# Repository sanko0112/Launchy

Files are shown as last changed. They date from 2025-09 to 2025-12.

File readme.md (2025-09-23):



### ESP32 ESP-NOW Based model rocket launch controller

## 🤌Features

- ESP-NOW Long range protocol
- Multi-layer safety: Key switch, iButton, push button
- OLED display for status feedback
- Built in battery charging circuit (TP4056)
- USB-C for programming/charging
- Internal 1S / External 2S battery selection for the e-match
- Continuity test (1S mode)
- Preheat mode(1S mode)
- Configurabe Countdown time, Ignition time
## 🔧Hardware

&nbsp;&nbsp;&nbsp;&nbsp;&nbsp;The system is based on a custom PCB designed in KiCad, built around the ESP32-C3-MINI-1 module. Both the transmitter and the igniter/receiver use the same board design, but are populated with different component sets depending on their role. The
hardware integrates Li-Ion charging (TP4056), a 3.3 V LDO regulator (AP2112K), a MOSFET-driven relay interface, iButton authentication, and status LEDs. USB-C is provided for charging and programming, while screw terminals allow safe connection of the igniter circuit.

&nbsp;&nbsp;&nbsp;&nbsp;&nbsp;Complete manufacturing files are available as a ZIP inside the GERBER folder as well as the BoM. Symbol and footprint libraries are uploaded so the project should be fully editable in KiCad now.

## 💻Firmware
### Transmitter.ino
- Handles the remote unit (user interface + iButton authentication).
- Implements menus for:
    - Battery type selection
    - Continuity check
    - Countdown time
    - Preheat start time
    - Preheat duration
    - Ignition delta
- Uses ESP-NOW to send launch and continuity test commands
- Provides OLED display feedback via LaunchDisplayLibrary
- Requires valid iButton for arming and launch
### Receiver.ino
- Handles the receiver unit (relay + buzzer)
- Waits for commands over ESP-NOW
- Performs continuity test by measuring V<sub>drop<sub>
- Executes countdown, preheat, and ignition relay control
- Includes buzzer startup sounds and launch feedback
### LaunchDisplayLibrary
- Custom display driver using U8g2 for SH1106 OLED.
- Provides functions for:
    - Splash/welcome screen
    - Authentication animations
    - Armed state screen (with T-, P_s, P_d, I_d values)
    - Countdown + preheat visual feedback
    - Ignition screen
    - Menus for parameter selection
### GetMacAddress.ino
- Utility to print the ESP32’s MAC address (used for setting ESP-NOW peers).
### ReadFob.ino
- Utility to read and print iButton IDs (used to whitelist authorized keys).
### Dependencies
#### [Arduino Core for ESP32](https://github.com/espressif/arduino-esp32)
### Libraries:
- esp_now.h (built-in)
- WiFi.h (built-in)
- esp_wifi.h (for long-range protocol mode)
- OneWire (for iButton reader)
- U8g2lib (for OLED display)
## 🚀 Setup & Upload
1. Clone repo and open in Arduino IDE.
2. Select ESP32 Dev Module (or your ESP32 board).
3. Upload separately:
    - Transmitter.ino → Remote unit
    - 2.Receiver.ino → Receiver unit
4. Use GetMacAddress.ino on each ESP32 to note their MAC addresses.
    - Update broadcastAddress[] in transmitter/receiver code accordingly.
5. Use Read_fob.ino to read your iButton ID.
    - Replace in allowedID[] array in the transmitter code.
## 📺 Display demo
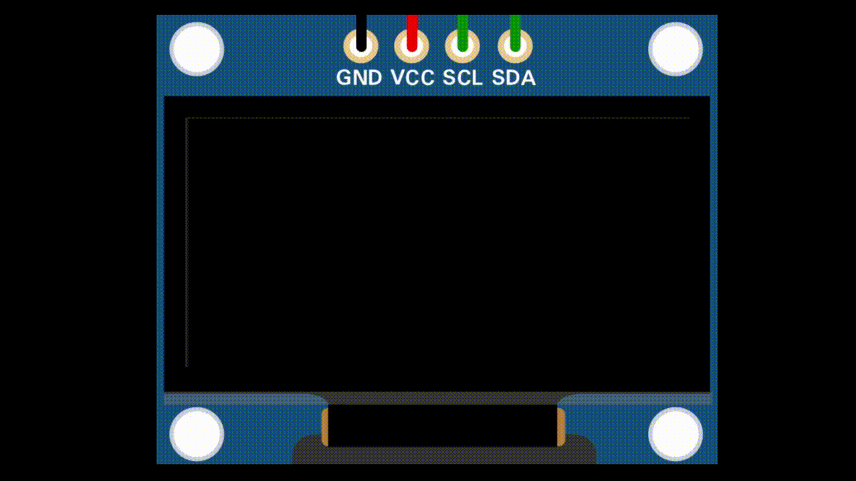
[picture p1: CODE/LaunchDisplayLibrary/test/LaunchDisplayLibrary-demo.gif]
Display


## 🔒 Safety

- Relay will not activate without valid iButton authentication.
- Launch packets use a session_id to prevent accidental re-triggering.
- Continuity test ensures igniter is properly connected before launch, if fails the system enters failsafe, requires full restart
## ✏️Schematic

Schematic

## 📷Images

### Transmitter
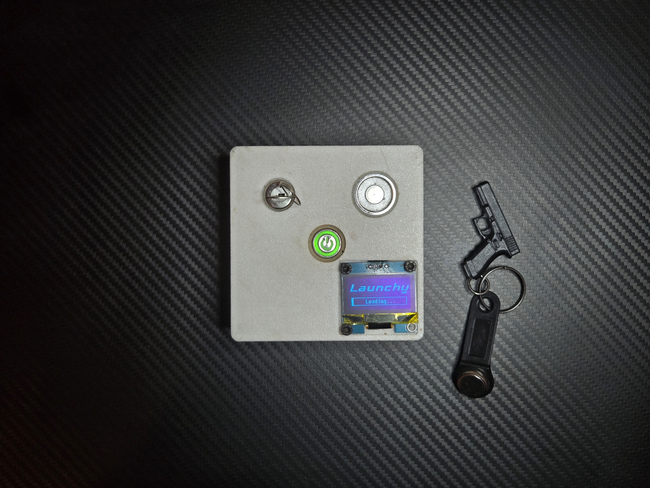
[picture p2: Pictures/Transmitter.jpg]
Transmitter

Transmitter-open

### Igniter
Igniter
Igniter-open

### Accessories
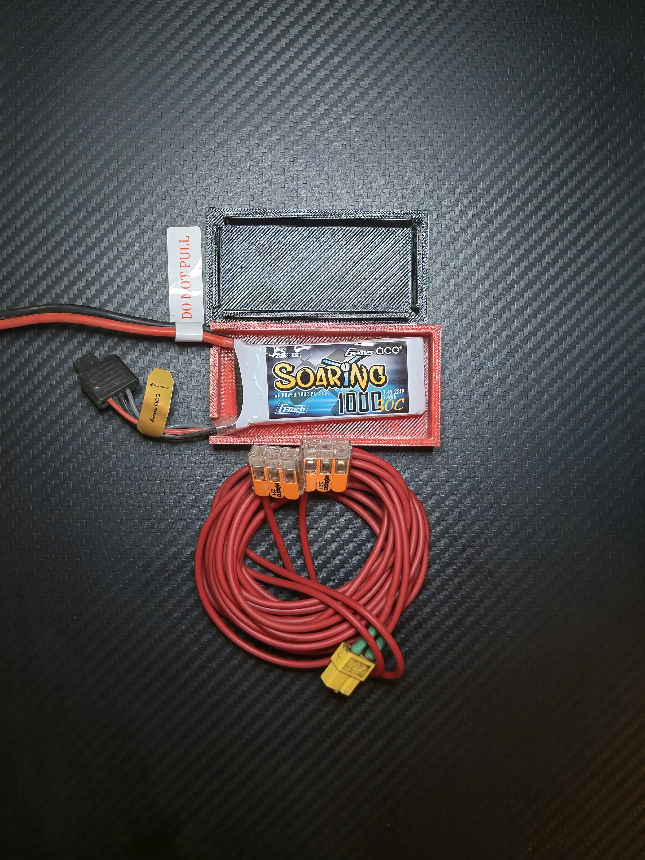
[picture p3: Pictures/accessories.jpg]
Accessories


## 🎥Demo

1S Demo (https://youtu.be/6urxjE-0fT8)

2S Demo (https://youtu.be/g8prIVViN2I)

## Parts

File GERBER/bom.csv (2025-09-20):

Designator | Footprint | Quantity | Value | LCSC Part #
+VBATT, GND | SolderWirePad_1x01_SMD_4x4mm | 2 | Conn_01x01_Socket
BOOT, J7 | PinHeader_1x02_P2.54mm_Vertical | 2 | Conn_01x02
C1, C2, C4, C5, C6 | 1206 | 5 | 10u
C3 | 1206 | 1 | 100n
D1, D2 | 1206 | 2 | LED
D3 | D_DO-201AD_P15.24mm_Horizontal | 1 | ~
IC1 | ESP32C3MINI1N4 | 1 | ESP32-C3-MINI-1-N4
J1 | PinHeader_2x06_P2.54mm_Vertical | 1 | Conn_02x06_Odd_Even
J5 | TerminalBlock_MaiXu_MX126-5.0-02P_1x02_P5.00mm | 1 | Screw_Terminal_01x02
J6 | USB_C_Receptacle_GCT_USB4105-xx-A_16P_TopMnt_Horizontal | 1 | USB_C_Receptacle_USB2.0_16P
K2 | SRD03VDCSLC | 1 | SRD-03VDC-SL-C
Q1 | SOT-23 | 1 | IRLML0030
R1, R10, R15, R5, R8 | 1206 | 5 | 10k
R11, R12, R13, R14, R2, R6 | 1206 | 6 | 5k1
R3 | 1206 | 1 | 0.4R
R4, R7 | 1206 | 2 | 1k
R9 | 1206 | 1 | 22k
U1 | SOT-23-5 | 1 | AP2112K-3.3
U2 | SOP127P600X175-9N | 1 | TP4056

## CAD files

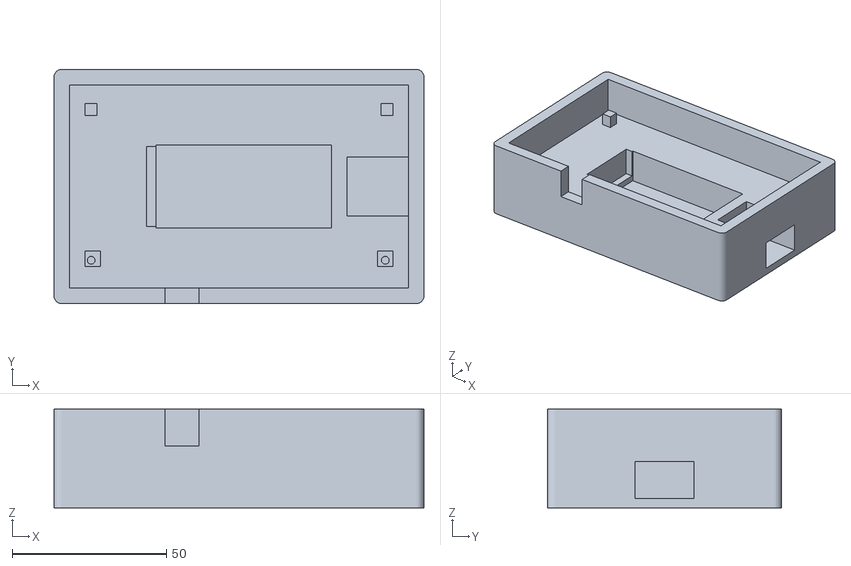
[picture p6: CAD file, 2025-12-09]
3D Models/Body1.stl
120.0 x 76.0 x 32.0

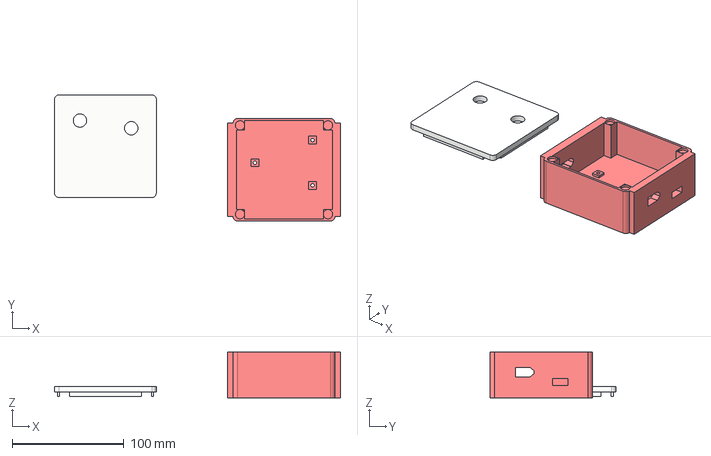
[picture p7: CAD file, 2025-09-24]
3D Models/Igniter enclosure.step
255.6 x 112.8 x 41.0 mm

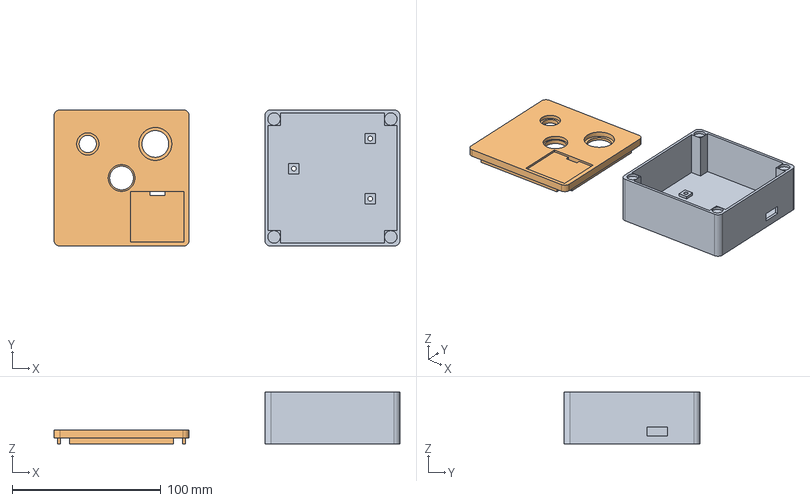
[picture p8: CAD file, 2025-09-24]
3D Models/Transmitter enclosure.step
233.0 x 91.8 x 35.0 mm

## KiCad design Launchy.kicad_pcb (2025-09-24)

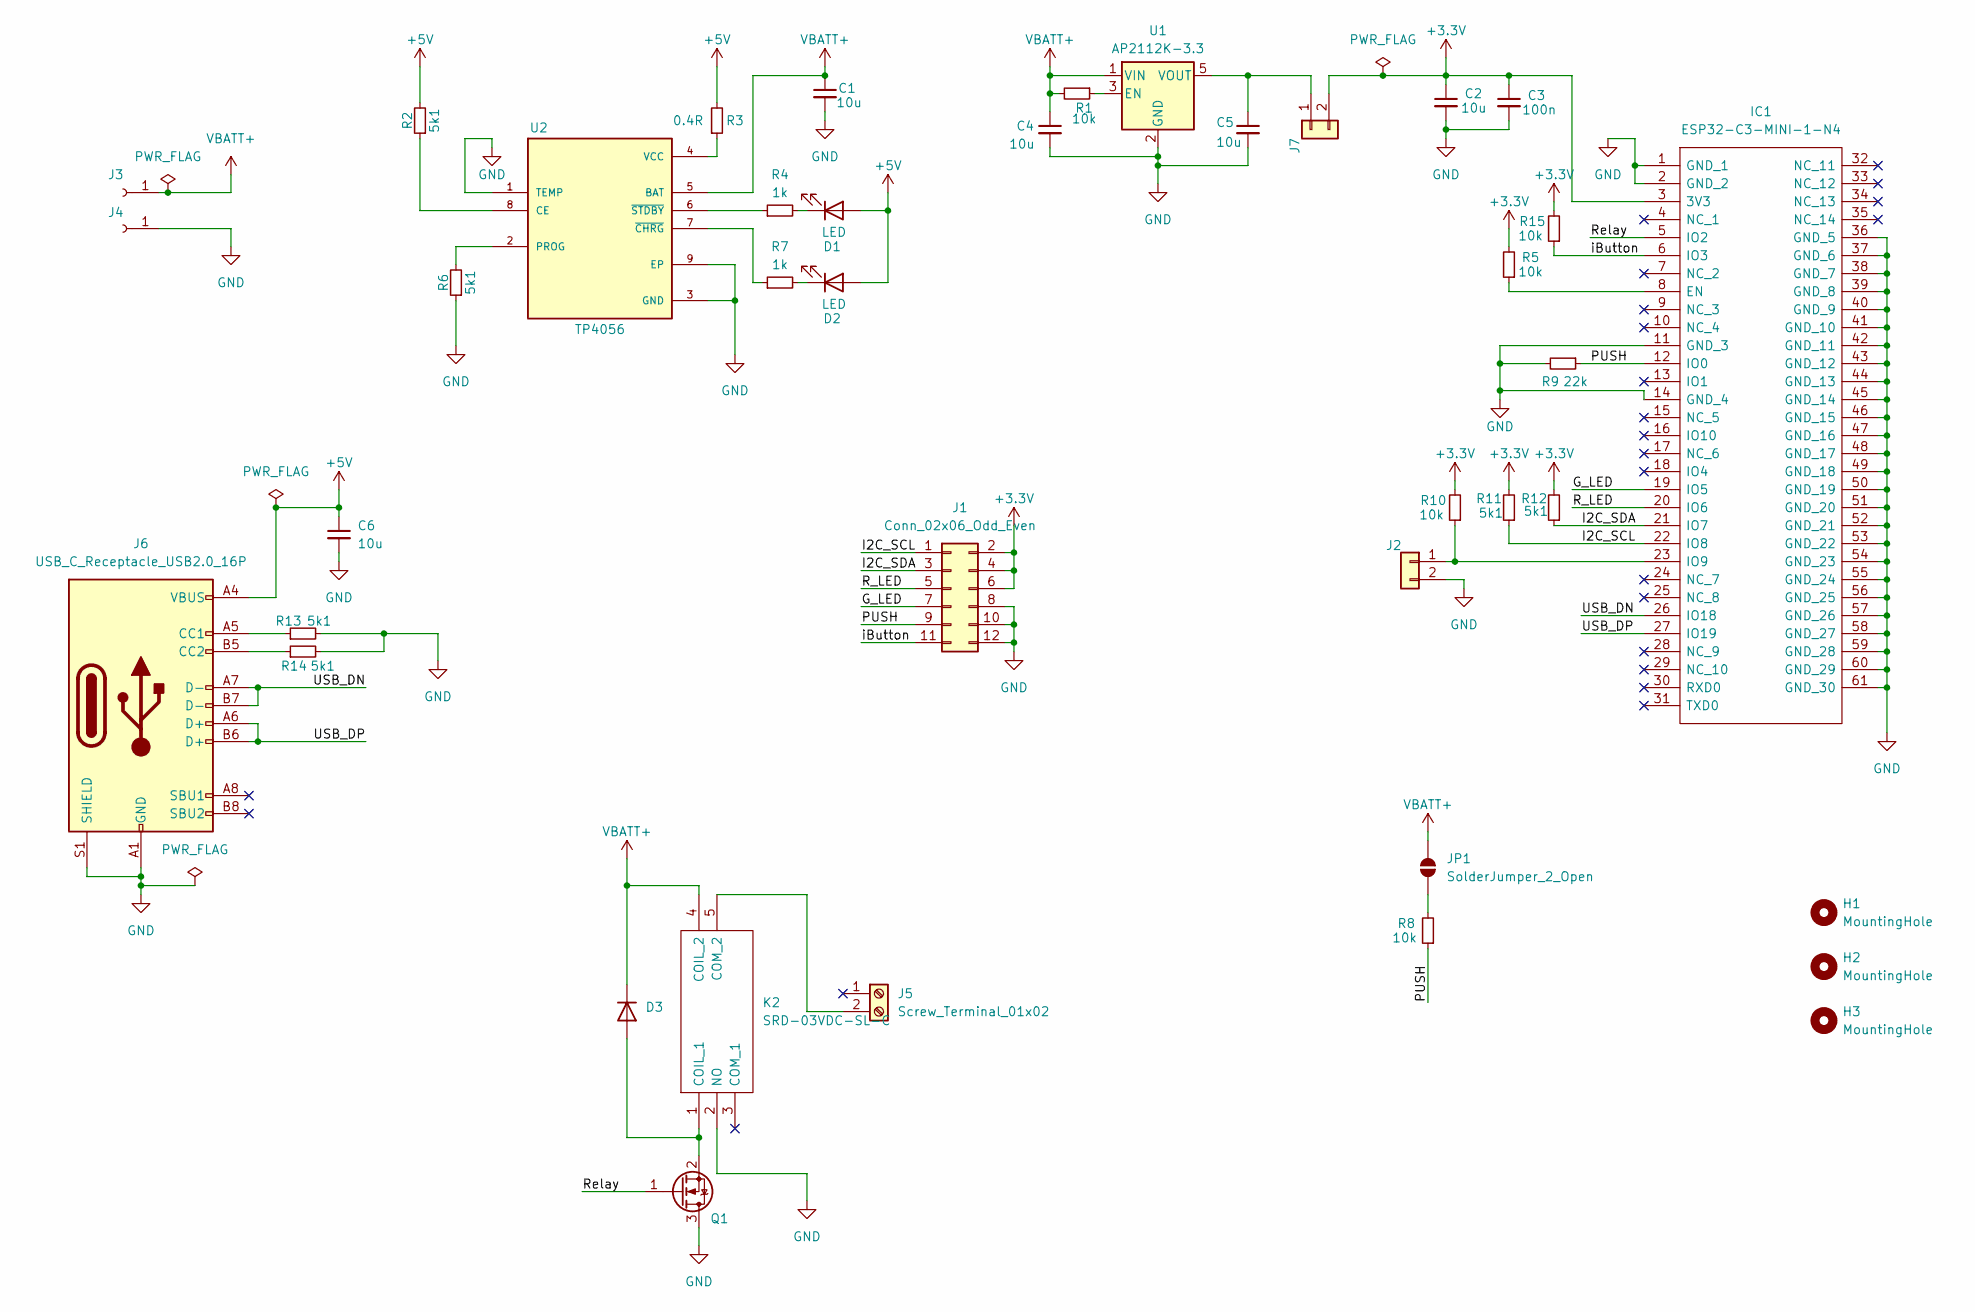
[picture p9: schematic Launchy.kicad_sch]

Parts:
C1, C2, C4, C5, C6: 10u; C_1206_3216Metric_Pad1.33x1.80mm_HandSolder
C3: 100n; C_1206_3216Metric_Pad1.33x1.80mm_HandSolder
D1, D2: LED; LED_1206_3216Metric_Pad1.42x1.75mm_HandSolder
D3: D_DO-201AD_P15.24mm_Horizontal
H1, H2, H3: MountingHole; MountingHole_3.2mm_M3
IC1: ESP32-C3-MINI-1-N4; ESP32C3MINI1N4; Manufacturer_Part_Number ESP32-C3-MINI-1-N4; Mouser Part Number 356-ESP32-C3-MINI1N4
J1: Conn_02x06_Odd_Even; PinHeader_2x06_P2.54mm_Vertical
J2, J7: Conn_01x02; PinHeader_1x02_P2.54mm_Vertical
J3, J4: Conn_01x01_Socket; SolderWirePad_1x01_SMD_4x4mm
J5: Screw_Terminal_01x02; TerminalBlock_MaiXu_MX126-5.0-02P_1x02_P5.00mm
J6: USB_C_Receptacle_USB2.0_16P; USB_C_Receptacle_GCT_USB4105-xx-A_16P_TopMnt_Horizontal
JP1: SolderJumper_2_Open; SolderJumper-2_P1.3mm_Open_TrianglePad1.0x1.5mm
K2: SRD-03VDC-SL-C; SRD03VDCSLC; Manufacturer_Part_Number SRD-03VDC-SL-C
Q1: IRLML0030; SOT-23
R1, R5, R8, R10, R15: 10k; C_1206_3216Metric_Pad1.33x1.80mm_HandSolder
R2, R6, R11, R12, R13, R14: 5k1; C_1206_3216Metric_Pad1.33x1.80mm_HandSolder
R3: 0.4R; C_1206_3216Metric_Pad1.33x1.80mm_HandSolder
R4, R7: 1k; C_1206_3216Metric_Pad1.33x1.80mm_HandSolder
R9: 22k; C_1206_3216Metric_Pad1.33x1.80mm_HandSolder
U1: AP2112K-3.3; SOT-23-5
U2: TP4056; SOP127P600X175-9N

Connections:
+3.3V: C2.1, C3.1, IC1.3 (3V3), J1.2, J1.4, J1.6, J7.2, R5.2, R10.2, R11.2, R12.2, R15.2
+5V: C6.1, D1.2 (A), D2.2 (A), J6.A4 (VBUS), J6.A9 (VBUS), J6.B4 (VBUS), J6.B9 (VBUS), R2.2, R3.2
/G_LED: IC1.19 (IO5), J1.7
/I2C_SCL: IC1.22 (IO8), J1.1, R11.1
/I2C_SDA: IC1.21 (IO7), J1.3, R12.1
/PUSH: IC1.12 (IO0), J1.9, R8.1, R9.1
/R_LED: IC1.20 (IO6), J1.5
/Relay: IC1.5 (IO2), Q1.1 (G)
/USB_DN: IC1.26 (IO18), J6.A7 (D-), J6.B7 (D-)
/USB_DP: IC1.27 (IO19), J6.A6 (D+), J6.B6 (D+)
/iButton: IC1.6 (IO3), J1.11, R15.1
GND: C1.2, C2.2, C3.2, C4.2, C5.2, C6.2, IC1.1 (GND_1), IC1.2 (GND_2), IC1.11 (GND_3), IC1.14 (GND_4), IC1.36 (GND_5), IC1.37 (GND_6), IC1.38 (GND_7), IC1.39 (GND_8), IC1.40 (GND_9), IC1.41 (GND_10), IC1.42 (GND_11), IC1.43 (GND_12), IC1.44 (GND_13), IC1.45 (GND_14), IC1.46 (GND_15), IC1.47 (GND_16), IC1.48 (GND_17), IC1.49 (GND_18), IC1.50 (GND_19), IC1.51 (GND_20), IC1.52 (GND_21), IC1.53 (GND_22), IC1.54 (GND_23), IC1.55 (GND_24), IC1.56 (GND_25), IC1.57 (GND_26), IC1.58 (GND_27), IC1.59 (GND_28), IC1.60 (GND_29), IC1.61 (GND_30), J1.8, J1.10, J1.12, J2.2, J4.1, J6.A1 (GND), J6.A12 (GND), J6.B1 (GND), J6.B12 (GND), J6.S1 (SHIELD), K2.2 (NO), Q1.3 (D), R6.1, R9.2, R13.2, R14.2, U1.2 (GND), U2.1 (TEMP), U2.3 (GND), U2.9 (EP); also elsewhere on the board
unnamed: D1.1 (K), R4.2
unnamed: D2.1 (K), R7.2
unnamed: D3.2 (A), K2.1 (COIL_1), Q1.2 (S)
unnamed: IC1.8 (EN), R5.1
unnamed 16: IC1.23 (IO9), J2.1, R10.1; also elsewhere on the board
unnamed: J5.2, K2.5 (COM_2)
unnamed: J6.A5 (CC1), R13.1
unnamed: J6.B5 (CC2), R14.1
unnamed: C5.1, J7.1, U1.5 (VOUT)
unnamed: JP1.2 (B), R8.2
unnamed: R1.1, U1.3 (EN)
unnamed: R2.1, U2.8 (CE)
unnamed: R6.2, U2.2 (PROG)
unnamed: R3.1, U2.4 (VCC)
unnamed: R7.1, U2.7 (~CHRG)
unnamed: R4.1, U2.6 (~STDBY)
VBATT+: C1.1, C4.1, D3.1 (K), J3.1, JP1.1 (A), K2.4 (COIL_2), R1.2, U1.1 (VIN), U2.5 (BAT); also elsewhere on the board

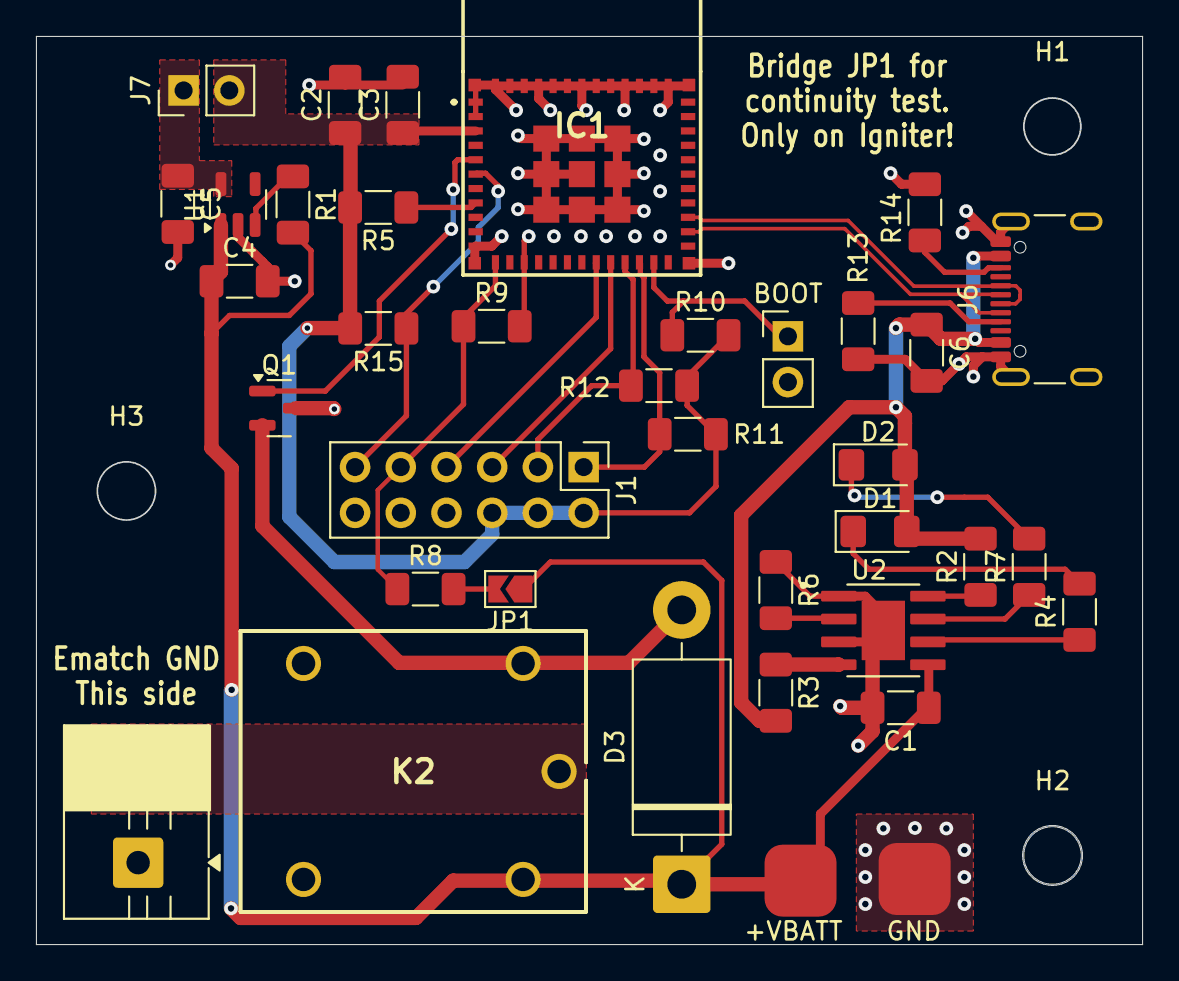
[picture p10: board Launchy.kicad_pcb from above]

Board: 2 copper layers, 61.5 x 50.5 mm, 40 parts (0 on the bottom side), 29 nets.

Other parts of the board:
+VBATT: Conn_01x01_Socket; SolderWirePad_1x01_SMD_4x4mm
BOOT: Conn_01x02; PinHeader_1x02_P2.54mm_Vertical
GND: Conn_01x01_Socket; SolderWirePad_1x01_SMD_4x4mm

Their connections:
GND: BOOT.2, GND.1; also elsewhere on the board
unnamed 16: BOOT.1; also elsewhere on the board
VBATT+: +VBATT.1; also elsewhere on the board

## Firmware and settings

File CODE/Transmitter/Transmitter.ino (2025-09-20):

#include <Arduino.h>
#include <esp_now.h>
#include <WiFi.h>
#include <OneWire.h>
#include <LaunchDisplayLibrary.h>
#include <esp_wifi.h>

//defines
#define iButton 3
#define togglesw 0
#define GREEN_LED 5
#define RED_LED 6

uint8_t launch_code;
int session_id;

uint8_t broadcastAddress[] = {0xAA, 0xBB, 0xCC, 0xDD, 0xEE, 0xFF}; // Igniter MAC-Address here

//iButton read declarations
OneWire ds(iButton);
byte storedID[8];
byte allowedID[8] = {0x00, 0x11, 0x22, 0x33, 0x44, 0x55, 0x66, 0x77}; // iButton fob ID here

uint8_t EN; // EN flag

esp_now_peer_info_t peerInfo;

uint8_t countdownTime = 5;
const int T_minValue = 3;
const int T_maxValue = 20;
bool countdown_confirmed = false;

uint8_t preheatStartTime = 3;
const int P_SminValue = 1;
int P_SmaxValue = 5;
bool preheat_start_confirmed = false;

float preheatDuration = 0.25;
const float durationResolution = 0.25;
const float P_DminValue = 0.25;
float P_DmaxValue = 5.0;
bool preheat_confirmed = false;

uint8_t ignitionDelta = 5;
const int I_DminValue = 1;
const int I_DmaxValue = 10;
bool ignitionDelta_confirmed = false;

uint8_t batt_type = 1;
bool batt_confirmed = false;

typedef struct struct_message {
uint8_t packet_type;
uint8_t batt_type;
uint8_t launch_code;
uint8_t countdownTime;
uint8_t preheatStartTime;
float preheatDuration;
float durationResolution;
uint8_t ignitionDelta;
int session_id;
} struct_message;

struct_message LaunchConfig;

typedef struct {
  uint8_t packet_type;
  bool continuity_result;
} continuity_response_t;

#define PACKET_TYPE_LAUNCH     0
#define PACKET_TYPE_CONTINUITY 1

uint8_t continuityTest_init = 5;
bool continuity_result = false;
bool recvFlag = false;
//function prototypes
void OnDataSent(const uint8_t *mac_addr, esp_now_send_status_t status);
void HandleSingleButton(void (*onShortPress)(), void (*onLongPress)());
void WaitForLaunchConfirm();
void iButtonAuth();
void blink(uint8_t pin, uint16_t times, uint16_t ms);
void reverseblink(uint8_t pin, uint16_t times, uint16_t ms);
void auth();

void setup() {

  Serial.begin(115200);
  Wire.begin(7, 8);
  u8g2.begin();
  delay(20);
  u8g2.clearBuffer();
  u8g2.sendBuffer();
  pinMode(GREEN_LED, OUTPUT); // Green_LED indicator
  pinMode(RED_LED, OUTPUT); // RED_LED indicator
  pinMode(togglesw, INPUT_PULLDOWN); // Toggle switch as input

  WiFi.mode(WIFI_STA);
  esp_wifi_set_protocol(WIFI_IF_STA, WIFI_PROTOCOL_LR);  // Long Range mode

  // Initilize ESP-NOW
  if (esp_now_init() != ESP_OK) {
    Serial.println("Error initializing ESP-NOW");
    return;
  }

  // Register the send callback
  // In setup() or once before any send
  esp_now_register_recv_cb(OnDataRecv);

  // Register peer
  memcpy(peerInfo.peer_addr, broadcastAddress, 6);
  peerInfo.channel = 0;  
  peerInfo.encrypt = false;
  draw_welcome();
  delay(500);
  loading();
}
 
void loop() {
  //checking for valid ibutton
  auth();
  delay(10);
  //valid ibutton found
  if(EN){

    digitalWrite (RED_LED, LOW);
    digitalWrite (GREEN_LED, HIGH);
    draw_auth_success();
    delay(500);
    
    //adding ESP-NOW peer
    if (!esp_now_is_peer_exist(broadcastAddress)) {
      if (esp_now_add_peer(&peerInfo) != ESP_OK) {
        Serial.println("Failed to add peer");
        return;
      }
      else{
        Serial.println(" added peer");
    }
    }
    delay(100);
    openBatteryTypeMenu();
    delay(300);
    if (batt_type == 1)
    { 
    continuity();
    s_settings();
    }
    else
    {
      ss_settings();
    }
    draw_armed();
    LaunchConfig.packet_type = PACKET_TYPE_LAUNCH;
    launch_code = 33;
    session_id = rand();
    LaunchConfig.launch_code = launch_code;
    LaunchConfig.batt_type = batt_type;
    LaunchConfig.countdownTime = countdownTime;
    LaunchConfig.preheatStartTime = preheatStartTime;
    LaunchConfig.preheatDuration = preheatDuration;
    LaunchConfig.durationResolution = durationResolution;
    LaunchConfig.ignitionDelta = ignitionDelta;
    LaunchConfig.session_id = session_id;
    delay(2000);
    //Waiting for button press
    WaitForLaunchConfirm();
    //sending launch command

    for(int j = 0; j<3; j++){
      LaunchConfig.packet_type = PACKET_TYPE_LAUNCH;
      esp_now_send(broadcastAddress, (uint8_t *)&LaunchConfig, sizeof(LaunchConfig));
    }
    //starting countdown
    countdown(countdownTime,preheatStartTime,preheatDuration);
    draw_ignition();
    delay(10);
    delay(ignitionDelta*1000);
    esp_now_del_peer(broadcastAddress); // Optional: prevent re-use until re-auth
    digitalWrite (GREEN_LED, LOW);
    delay(20);
    digitalWrite (RED_LED, HIGH);
    EN = 0;
  }
  //ibutton auth failed retrying...
  else{
    auth();
  }
}


void iButtonAuth()
{
  //initializing
  byte addr[8];
  if (!ds.search(addr)) {
    ds.reset_search();
    return;
  }
  //checking iButton type
  if (OneWire::crc8(addr, 7) != addr[7]) {
    Serial.println("CRC is not valid!");
    return;
  }
  //storing recieved ID
  for (int i = 0; i < 8; i++) {
    storedID[i] = addr[i];
  }
  //checking if recieved ID is matching the stored ID
  bool isAuth = true;
  for (int i = 0; i < 8; i++) {
    if (storedID[i] != allowedID[i]) {
      isAuth = false;
    }
  }
  //matching ID EN flag TRUE
  if (isAuth) {
    Serial.println(" -> AUTHORIZED");
    EN = 1;
  }
  //mismatch on ID's EN flag stays FALSE
  else {
    Serial.println("FAILED");
    reverseblink(RED_LED, 2, 200);
    EN = 0;
  }
  delay(200);
}

void HandleSingleButton(void (*onShortPress)(), void (*onLongPress)()) {
  const unsigned long longPressTime = 1000; // 1 second hold
  unsigned long pressStart = 0;
  bool isPressed = false;
  bool longPressTriggered = false;

  while (true) {
    int state = digitalRead(togglesw);

    if (state == HIGH) {
      if (!isPressed) {
        pressStart = millis();
        isPressed = true;
      } else if (!longPressTriggered && (millis() - pressStart >= longPressTime)) {
        longPressTriggered = true;
        onLongPress();  // Immediately trigger long press
        break;
      }
    } else if (state == LOW && isPressed) {
      // Button released before long press time
      if (!longPressTriggered) {
        onShortPress();  // Short press handler
      }
      break;
    }

    delay(10);
  }
}

void WaitForLaunchConfirm() {
  Serial.println("Hold to launch...");
  HandleSingleButton([]() {}, []() {
    Serial.println("Launch confirmed.");
    // Proceed with countdown + ignition
  });
}

void blink(uint8_t pin, uint16_t times, uint16_t ms)
{
  for (uint16_t i = 0; i< times; i++){
    digitalWrite(pin, HIGH);
    delay(ms);
    digitalWrite(pin, LOW);
    delay(ms);
  }
}

void reverseblink(uint8_t pin, uint16_t times, uint16_t ms)
{
  for (uint16_t i = 0; i< times; i++){
    digitalWrite(pin, LOW);
    delay(ms);
    digitalWrite(pin, HIGH);
    delay(ms);
  }
}


void auth()
{ 
  while(1){
    draw_auth_a();
    iButtonAuth();
    delay(100);
    draw_auth_b();
    iButtonAuth();
    delay(100);
    draw_auth_c();
    iButtonAuth();
    delay(100);
    if(EN)
      break;
    draw_auth_d();
    iButtonAuth();
    delay(100);
    if(EN)
      break;    
    draw_auth_e();
    iButtonAuth();
    delay(100);
    if(EN)
      break;    
    draw_auth_f();
    iButtonAuth();
    delay(100);
    if(EN)
      break;    
    draw_auth_g();
    
    iButtonAuth();
    delay(100);
    if(EN)
      break;
  }   
}

void updateCountdownText() {
  itoa(countdownTime, countdown_menu_var, 10);
}

void onShortPress_CountdownMenu() {
  countdownTime++;
  if (countdownTime > T_maxValue) countdownTime = T_minValue;
  updateCountdownText();
  draw_countdown_menu();
}

void onLongPress_CountdownMenu() {
  countdown_confirmed = true;
  Serial.print("Countdown set to: ");
  Serial.println(countdownTime);
}

void openCountdownMenu() {
  countdown_confirmed = false;
  updateCountdownText();
  draw_countdown_menu();

  while (!countdown_confirmed) {
    HandleSingleButton(onShortPress_CountdownMenu, onLongPress_CountdownMenu);
  }
}


void updatePreheatStartText() {
  itoa(preheatStartTime, preheat_start_menu_var, 10);
}

void onShortPress_PreheatStartMenu() {
  preheatStartTime++;
  if (preheatStartTime > P_SmaxValue) preheatStartTime = P_SminValue;
  updatePreheatStartText();
  draw_preheat_start_menu();
}

void onLongPress_PreheatStartMenu() {
  preheat_start_confirmed = true;
  Serial.print("Preheat start time set to: T-");
  Serial.println(preheatStartTime);
}

void openPreheatStartMenu() {
  preheat_start_confirmed = false;
  updatePreheatStartText();
  draw_preheat_start_menu();
  delay(400);

  while (!preheat_start_confirmed) {
    HandleSingleButton(onShortPress_PreheatStartMenu, onLongPress_PreheatStartMenu);
  }
}


void updatePreheatText() {
  dtostrf(preheatDuration, 3, 2, preheat_duration_menu_var);
}

void onShortPress_PreheatMenu() {
  preheatDuration += durationResolution;
  if (preheatDuration > P_DmaxValue) preheatDuration = P_DminValue;
  updatePreheatText();
  draw_preheat_duration_menu();
}

void onLongPress_PreheatMenu() {
  preheat_confirmed = true;
  Serial.print("Preheat set to: ");
  Serial.println(preheatDuration);
}

void openPreheatDurationMenu() {
  preheat_confirmed = false;
  updatePreheatText();
  draw_preheat_duration_menu();
  delay(400);
  while (!preheat_confirmed) {
    HandleSingleButton(onShortPress_PreheatMenu, onLongPress_PreheatMenu);
  }
}

void updateIgnitionDeltaText() {
  itoa(ignitionDelta, ignition_delta_menu_var, 10);
}

void onShortPress_IgnitionMenu() {
  ignitionDelta++;
  if (ignitionDelta > I_DmaxValue) ignitionDelta = I_DminValue;
  updateIgnitionDeltaText();
  draw_ignition_delta_menu();
}

void onLongPress_IgnitionMenu() {
  ignitionDelta_confirmed = true;
  Serial.print("Ignition Delta is set to: ");
  Serial.println(ignitionDelta);
}

void openIgnitionDeltaMenu() {
  ignitionDelta_confirmed = false;
  updateIgnitionDeltaText();
  draw_ignition_delta_menu();
  delay(400);
  while (!ignitionDelta_confirmed) {
    HandleSingleButton(onShortPress_IgnitionMenu, onLongPress_IgnitionMenu);
  }
}

void s_settings(void)
{
draw_countdown_menu();
delay(300);
openCountdownMenu();
P_SmaxValue = countdownTime;
openPreheatStartMenu();
P_DmaxValue = preheatStartTime-0.75;
openPreheatDurationMenu();
openIgnitionDeltaMenu();

itoa(countdownTime, armed_t_, 10);
itoa(preheatStartTime, armed_ps, 10);
itoa(preheatDuration, armed_pd, 10);
itoa(ignitionDelta, armed_id, 10);
/*
int launch_code;
int countdownTime;
int preheatStartTime;
float preheatDuration;
int ignitionDelta;
*/
}
void ss_settings(void)
{
openCountdownMenu();
P_SmaxValue = countdownTime;
openIgnitionDeltaMenu();
itoa(countdownTime, armed_t_, 10);
itoa(preheatStartTime, armed_ps, 10);
itoa(preheatDuration, armed_pd, 10);
itoa(ignitionDelta, armed_id, 10);
/*
int launch_code;
int countdownTime;
int preheatStartTime;
float preheatDuration;
int ignitionDelta;
*/
}
void OnDataRecv(const esp_now_recv_info_t *recv_info, const uint8_t *incomingData, int len) {
    if (len == sizeof(continuity_response_t)) {
        continuity_response_t response;
        memcpy(&response, incomingData, len);
        if (response.packet_type == PACKET_TYPE_CONTINUITY) {
            continuity_result = response.continuity_result;
            Serial.print("Received continuity result: ");
            Serial.println(continuity_result);
        }
    }
  recvFlag = true;  
}


void continuity() {

  Serial.println("Press and hold to begin continuity test...");
  draw_continuity_check_start();
  delay(1000);
  HandleSingleButton([]() {}, []() {
    Serial.println("Continuity test started");

    struct_message continuity_packet = {};
    continuity_packet.packet_type = PACKET_TYPE_CONTINUITY;
    esp_now_send(broadcastAddress, (uint8_t *)&continuity_packet, sizeof(continuity_packet));
    unsigned long startTime = millis();
    while ( millis() - startTime < 1500) {
      delay(10); // yield time for callback
    }
        if (continuity_result) {
          Serial.println("Continuity success. Hold to continue...");
          draw_continuity_check_success();
          HandleSingleButton([]() {}, []() {
          Serial.println("Continuing...");
          delay(400);
          });
        } else {
          Serial.println("Continuity failed. Check connection and retry.");
          draw_continuity_check_failed();
          while(1){}
         // wait forever or implement retry
        }
     
  });
}

// ===== Battery type menu =====
// 1S = 1, 2S = 2


// Show the right screen for current selection
void draw_batt_current() {
  if (batt_type == 1) {
    draw_batt_s();   // your "1S selected" screen
  } else {
    draw_batt_ss();  // your "2S selected" screen
  }
}

// Short press: toggle 1S <-> 2S
void onShortPress_BattMenu() {
  batt_type = (batt_type == 1) ? 2 : 1;
  draw_batt_current();
}

// Long press: confirm selection
void onLongPress_BattMenu() {
  batt_confirmed = true;
  Serial.print("Battery type set to: ");
  Serial.println(batt_type == 1 ? "1S" : "2S");
  Serial.println(batt_type);
}

// Open the menu and wait for confirmation
void openBatteryTypeMenu() {
  batt_confirmed = false;
  draw_batt_current();
  delay(300);

  while (!batt_confirmed) {
    HandleSingleButton(onShortPress_BattMenu, onLongPress_BattMenu);
  }
}

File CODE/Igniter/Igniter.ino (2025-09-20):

  #include <esp_now.h>
  #include <WiFi.h>
  #include <esp_wifi.h>

  // Pin definitions
  #define RELAY_PIN 2
  #define BUZZ 3
  #define ADC_PIN 0

  // Launch code value to match
  typedef struct struct_message {
  uint8_t packet_type;
  uint8_t batt_type;
  uint8_t launch_code;
  uint8_t countdownTime;
  uint8_t preheatStartTime;
  float preheatDuration;
  float durationResolution;
  uint8_t ignitionDelta;
  int session_id;
  } struct_message;
  
  struct_message LaunchConfig;
  
  int lastSession_id = 4;

  typedef struct {
  uint8_t packet_type;
  uint8_t continuity_result;
  } continuity_response_t;

  uint8_t continuity_result = 0;

  #define PACKET_TYPE_LAUNCH     0
  #define PACKET_TYPE_CONTINUITY 1

  uint8_t broadcastAddress[] = {0xAA, 0xBB, 0xCC, 0xDD, 0xEE, 0xFF}; // Transmitter MAC-Address here


  // Setup function
  void setup() {
    Serial.begin(115200);

    // Initialize pins
    pinMode(RELAY_PIN, OUTPUT);
    pinMode(BUZZ, OUTPUT);
    digitalWrite(RELAY_PIN, LOW);   // Relay OFF
    digitalWrite(BUZZ, LOW);  // Buzzer OFF

    // Set WiFi to station mode
    WiFi.mode(WIFI_STA);
    esp_wifi_set_protocol(WIFI_IF_STA, WIFI_PROTOCOL_LR);  // Long Range mode


    // Initialize ESP-NOW
    if (esp_now_init() != ESP_OK) {
      Serial.println("Error initializing ESP-NOW");
      return;
    }
    esp_now_peer_info_t peer;
    memset(&peer, 0, sizeof(peer));
    memcpy(peer.peer_addr, broadcastAddress, 6);
    peer.channel = 0;
    peer.encrypt = false;

    if (!esp_now_is_peer_exist(peer.peer_addr)) {
      esp_err_t addStatus = esp_now_add_peer(&peer);
    if (addStatus != ESP_OK) {
      Serial.println("Failed to add transmitter as peer!");
  }
}
    // Register receive callback
    esp_now_register_recv_cb(OnDataRecv);
    Serial.println("Receiver ready. Waiting for peer auth and launch command...");
    startup_sound();
  }

  // Loop does nothing, waiting for data via callback
  void loop() {
    delay(10);
  }

  // Callback function when data is received
void OnDataRecv(const esp_now_recv_info_t *recv_info, const uint8_t *incomingData, int len) {
  struct_message msg;
  memcpy(&msg, incomingData, sizeof(msg));
  if (msg.packet_type == PACKET_TYPE_CONTINUITY) {
    int adcVal = 0;
    int freeValue = 5000;
    int loadValue = 5000;
    for (int q = 0; q<5; q++)
    {
      adcVal = analogRead(ADC_PIN);
      if (adcVal < freeValue){
        freeValue = adcVal;
      }
      delay(20);
    }
    digitalWrite(RELAY_PIN, HIGH);
    for(int p = 0; p<10;p++)
    {
      adcVal = analogRead(ADC_PIN);
      if (adcVal < loadValue){
        loadValue = adcVal;
      }
      delay(50);
    }
    digitalWrite(RELAY_PIN, LOW);
    Serial.println("freeValue");
    Serial.println(freeValue);
    Serial.println("loadValue");
    Serial.println(loadValue);
    if(loadValue<=freeValue-20)
    {
      continuity_result = true;
    }
    else
    {
      continuity_result = false;
    }
    continuity_response_t response;
    response.packet_type = PACKET_TYPE_CONTINUITY;
    response.continuity_result = continuity_result;

    for (int k = 0; k < 5; k++) {
      esp_now_send(broadcastAddress, (uint8_t *)&response, sizeof(response));
    }
    Serial.println(continuity_result);
    if (continuity_result)
    {
       onReceive_sound(2);
    }
    else{fail_sound();}
    delay(100);
  }
  if (msg.packet_type == PACKET_TYPE_LAUNCH && msg.session_id != lastSession_id) {
    lastSession_id = msg.session_id;
    LaunchConfig = msg;
    uint8_t batteryType;
    batteryType = LaunchConfig.batt_type;
    Serial.println(batteryType);
    if (batteryType == 1) {
      TickType_t lastWakeTime = xTaskGetTickCount();
      int durationResolution_ms = LaunchConfig.durationResolution * 1000;
      int preheatDuration_ms = LaunchConfig.preheatDuration * 1000;
      int preheatStart_ms = LaunchConfig.preheatStartTime * 1000;
      int countdown_ms = LaunchConfig.countdownTime * 1000-250;     //countdown-onReceive_sound
      onReceive_sound(5);
      if (LaunchConfig.launch_code == 33) {
        for (int t = countdown_ms; t >= 0; t -= durationResolution_ms) {
        // Start preheat when time left <= preheatStart and there's preheat duration remaining
          if (t <= preheatStart_ms && preheatDuration_ms > 0) {
          digitalWrite(RELAY_PIN, HIGH);  // Relay ON (preheat)
          digitalWrite(BUZZ, HIGH);
          preheatDuration_ms -= durationResolution_ms;
          } else {
          digitalWrite(RELAY_PIN, LOW); // Relay OFF
          digitalWrite(BUZZ, LOW);
         }

          vTaskDelayUntil(&lastWakeTime, pdMS_TO_TICKS(durationResolution_ms));
        }

        // IGNITION PHASE
        digitalWrite(RELAY_PIN, HIGH);  // Relay ON (ignite)
        digitalWrite(BUZZ, HIGH);
        delay(LaunchConfig.ignitionDelta * 1000);
        digitalWrite(RELAY_PIN, LOW); // Relay OFF
        digitalWrite(BUZZ, LOW); // Relay OFF
      }
    }
    else
    {
      TickType_t lastWakeTime = xTaskGetTickCount();
      int countdown_ms = LaunchConfig.countdownTime * 1000-250;
      int durationResolution_ms = LaunchConfig.durationResolution * 1000;     //countdown-onReceive_sound
      onReceive_sound(5);
      if (LaunchConfig.launch_code == 33) {
        for (int t = countdown_ms; t >= 0; t -= durationResolution_ms) {
          vTaskDelayUntil(&lastWakeTime, pdMS_TO_TICKS(durationResolution_ms));
        }
      }
      // IGNITION PHASE
      digitalWrite(RELAY_PIN, HIGH);  // Relay ON (ignite)
      digitalWrite(BUZZ, HIGH);
      delay(LaunchConfig.ignitionDelta * 1000);
      digitalWrite(RELAY_PIN, LOW); // Relay OFF
      digitalWrite(BUZZ, LOW); // Relay OFF
    }
  }
}
 void startup_sound()
{
    digitalWrite(BUZZ, HIGH);
    delay(300);
    digitalWrite(BUZZ, LOW);
    delay(300);
    digitalWrite(BUZZ, HIGH);
    delay(75);
    digitalWrite(BUZZ, LOW);
    delay(75);
    digitalWrite(BUZZ, HIGH);
    delay(75);
    digitalWrite(BUZZ, LOW);
    delay(75);
}
  void onReceive_sound(int times)
  {
    for(int i = 0; i < times; i++)
    {
    digitalWrite(BUZZ, HIGH);
    delay(50);
    digitalWrite(BUZZ, LOW);
    delay(50);
    }
  }
void fail_sound()
{
    digitalWrite(BUZZ, HIGH);
    delay(300);
    digitalWrite(BUZZ, LOW);
    delay(300);
    digitalWrite(BUZZ, HIGH);
    delay(300);
    digitalWrite(BUZZ, LOW);
    delay(300);
    digitalWrite(BUZZ, HIGH);
    delay(300);
    digitalWrite(BUZZ, LOW);
    delay(300);
}

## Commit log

2025-09-20 Quality of life changes in Code Symbol and footprint libraries include Schematic and pcb updates, unnecessary dual bjt remove, replacing 2.00mm headers with more common 2.54mm ones Copper Pour tweaks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
    [LaunchControl-B_Courtyard.gbr, LaunchControl-B_Cu.gbl, LaunchControl-B_Fab.gbr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]
2025-09-20 updated Schematic in README
2025-09-24 added board 3d model
    [Launchy.kicad_pcb]
2025-09-24 deleted unnecesary 3D models
    [Igniter board.stl, Transmitter board.stl]
2025-09-24 swapped stl models to stp for extra texture
    [Igniter enclosure.step, Igniter enclosure.stl, Transmitter enclosure.step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]
